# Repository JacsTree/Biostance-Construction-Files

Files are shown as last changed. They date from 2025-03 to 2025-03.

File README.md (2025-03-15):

# Biostance Device Assembly Instructions
This document is written for Northwestern DTC 1 Section 5.1.

*Adapted from the docs [here](https://docs.google.com/document/d/1ldEVrvwhGYVu4OGukCBJCGcmKfjVL98Qq2BRzPFvP7Y/edit?usp=sharing): (additional pictures can be found at the link)* 
## Introduction

This document provides step-by-step instructions for reproducing the final Biostance device prototype.  It covers the process from purchasing parts and assembling components to final construction and code implementation.  The device measures and logs a user's percent weight-bearing status over time.

**Estimated Assembly Time:** 9 hours (excluding drying/printing times) for someone proficient in the required techniques with pre-prepared materials.

**Skill Level:** Intermediate to advanced proficiency in 3D printing, soldering, woodworking/plastic cutting, and basic electronics.

**Recommendation:**  Read through *all* instructions and gather *all* materials and tools before starting.

## Parts List

### Components

| Component | Quantity | Notes |
| :--- | :--- | :--- |
| 50kg Load Cells | 8 | |
| Microcontroller (ESP32) | 1 | |
| PLA Filament (1.75mm) | 100g |  Color of your choice |
| 22 Gauge Wire | 8 x 1.5ft| Multiple Colors is helpful |
| 22 Gauge Wire | 8 x 8in  | Multiple Colors is helpful |
| Lithium Cell Battery | 1 |  Capacity and voltage compatible with your ESP32 (check specifications) |
| Battery Charger | 1 |  Compatible with your chosen battery |
| Grip Tape Roll | 1 x 30ft | |
| Hot Glue Sticks | 2 | |
| Epoxy Packets | 8 | |
| Rubber Feet Package | 1 | |
| Rosin Core Solder Wire | 3g | |
| Sturdy Material (Wood/Polycarb) | 3ft x 3ft | |
| 2 or 3-way Switch | 1 | |

### Tools

| Tool | Notes |
| :--- | :--- |
| 3D Printer |  With sufficient build volume for the largest part. |
| Bandsaw or Table Saw |  For cutting the base material. |
| Tape Measure | |
| Ruler | |
| Soldering Iron | |
| Wire Strippers | |
| Scissors | |
| Hot Glue Gun | Optional, but helpful for securing components. |
| Multimeter | Optional, but helpful for testing connections. |
| Razor Blade |  For cleaning up grip tape edges. |

## Safety Precautions

**Crucially, follow all safety instructions provided with your tools and materials.**  In addition, observe these precautions:

*   **Heat-Based Devices (3D Printer, Soldering Iron, Hot Glue Gun):**
    *   **Do NOT touch heated surfaces (nozzles, beds, etc.) until fully cooled.**
    *   **Do NOT touch melted material (filament, solder, glue) during operation.**
    *   **Allow sufficient cooling time for wires, PCB boards, and components near solder joints.  Heat can conduct through these parts.**
    *   Work in a well-ventilated area.

*   **Cutting Devices (Saws, Wire Strippers, Scissors, Razor Blade, Tape Measure):**
    *   **Exercise extreme caution to avoid cuts from sharp edges.**
    *   **Bandsaws/Table Saws present significant risks. Materials, clothing, or body parts can be caught and pulled into the blade.**
    *   **Operate these saws with *utmost* caution and follow *all* manufacturer safety guidelines.**
    *   Use appropriate safety equipment (eye protection, push sticks, etc.).
    *   Ensure the work area is clear of obstructions.
    *   Never reach over the blade.

* **Epoxy**
    * Work in a well ventilated area.
    * Wear gloves
    * Do not ingest

## Construction Steps

### Step 1: 3D Printing

1.  **File Locations:**
    *   **GitHub (this repository):**
        *   `Top of Box v2.stl`
        *   `Bottom of Box v4.stl` (Adjust file if using different bottom material thickness)
        *   `tip scale v2.stl`
    *   **Thingiverse (patrick3345):**
        *   `50kg Loadcell Bracket versionF`  [Link to Thingiverse page](https://www.thingiverse.com/thing:2624188/files) 

2.  **Printing Instructions:**
    *   Combine all files into a single print job if your build plate is large enough.
    *   **Slicer Settings:**
        *   Wall Thickness: 1.0 mm
        *   Infill: 50%
        *   Supports: Tree-style (auto-generated) 
        *   Recommended Slicers: Cura Slicer, PrusaSlicer, or Bambu Studio (Instructions below use Cura Slicer).
    *   **Placement:** Ensure models are *not* overlapping on the build plate.

4.  **Slice and Upload:** Slice the files using your chosen slicer and upload them to your 3D printer. Follow your printer's specific instructions for uploading files.

5.  **Post-Processing:**
    *   Allow the build plate to cool completely.
    *   Carefully remove the printed parts from the build plate.
    *   Remove any support structures.

### Step 2: Cut Structure Pieces and Assemble Base

1.  **Cutting:** Cut the sturdy material (wood/polycarbonate) into:
    *   One piece: 1.5ft x 3ft
    *   Two pieces: 1.5ft x 1.5ft

3.  **Load Cell Holder Placement:**
    *   Position the eight 3D-printed load cell holders on the *underside* of the 1.5ft x 3ft piece. These should be located where the corners of the 1.5ft x 1.5ft plates will eventually sit (refer to the image in the original instructions, which you should ideally include).
    *   **Securely epoxy the load cell holders in place.** Allow ample drying time according to the epoxy's instructions.

4.  **Rubber Feet:**
    *   Flip the 1.5ft x 3ft piece over.
    *   Attach rubber feet to the *opposite* side (the side *without* the load cell holders).  These should be positioned to align with the load cell holders.
    *   Epoxy the rubber feet in place.

5.  **Grip Tape (Top Pieces):**
    *   Apply grip tape to the *top* surfaces of the two 1.5ft x 1.5ft plates.
    *   Use a razor blade to carefully trim any excess grip tape for clean edges.

6.  **Load Cell Tips:**
    *   Attach the 3D-printed "tip scale v2.stl" pieces to the *top* of the 1.5ft x 1.5ft plates.
    *   Position each tip so it aligns with the *center* of a corresponding load cell holder on the base piece.
    *   Epoxy the tips in place.

### Step 3: Electronics, Wiring, and First Calibration

**Wiring Diagram:** Follow this diagram carefully throughout the wiring process.

**(Figure 1: Electronics wiring diagram displaying the function of each part.** 
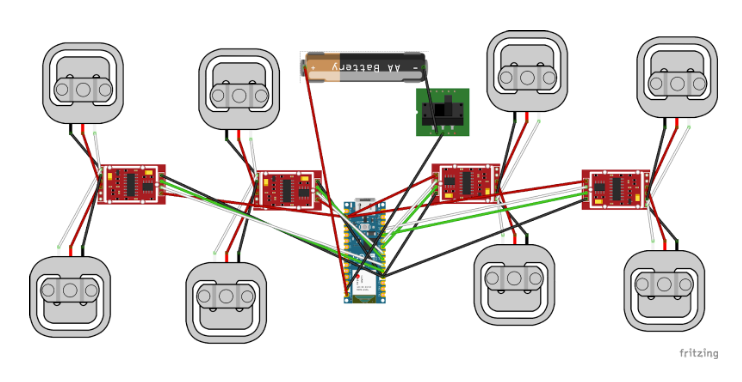
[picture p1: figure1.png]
Wiring Diagram

1.  **HX711 Modification (80Hz Mode):**
    *   **De-solder the 0 Ohm resistor** from *each* HX711 chip.
    *   **Bridge the 80Hz pads** with solder. This enables faster data transfer (at the cost of some accuracy).

2.  **Load Cell Wiring:** Solder the wires from *each* load cell to its corresponding HX711 module as shown in the wiring diagram.  **The colors of the load cell wires may vary; use a multimeter to identify the correct wires if necessary.**

3.  **HX711 Wire Lengths:**
    *   Attach approximately 1.3ft wires to the `VCC`, `GND`, `DT`, and `SCK` pins on *two* of the HX711 boards.  These will be the "outer" boards.
    *   Attach 8-inch wires to the `VCC`, `GND`, `DT`, and `SCK` pins on the other *two* HX711 boards.
    *   Place all load cells into their holders on the bottom piece, with the wires facing upwards.

4.  **HX711 to ESP32 Connections:**
    *   Solder the `DT` (Data) and `SCK` (Clock) pins from each HX711 to the appropriate GPIO pins on your ESP32, according to the wiring diagram.
    *   **If you use a different ESP32 board, you can choose different GPIO pins, but *you must update the pin numbers in the code accordingly*.**
    *   Connect all HX711 `VCC` pins together and then to a 3.3V or 5V pin on the ESP32 (depending on your ESP32's specifications and the HX711 operating voltage - check datasheets!).
    *   Connect all HX711 `GND` pins together and then to a `GND` pin on the ESP32.

5.  **Battery and Switch Wiring:**
    *   Solder the *negative* (-) wire from the battery connector to one terminal of the switch.
    *   Solder a wire from the *other* terminal of the switch to the `GND` pin of the ESP32.
    *   Solder the *positive* (+) wire from the battery connector to the `Vin` pin on the ESP32.
    *   **CRITICAL WARNING:** **If your battery voltage exceeds the ESP32's maximum input voltage (check the ESP32 datasheet!), you *must* add a voltage regulator (e.g., a 5V regulator) between the battery and the ESP32's `Vin` pin.  Failure to do so will damage the ESP32 and could cause a fire.**

6.  **Calibration (Test Code):**
    *   Upload the test code [here](https://github.com/bogde/HX711/blob/master/examples/HX711_full_example/HX711_full_example.ino) to the ESP32 using the Arduino IDE 2.x.
    *   **Arduino IDE Setup:**
        *   Ensure you have the ESP32 board definitions installed in the Arduino IDE.
        *   Select the correct ESP32 board and port.
        *   Set the "Partition Scheme" to a large enough size to accommodate the compiled code.
    *   **Calibration Procedure:** Follow the instructions *within the test code* to determine the calibration factor for *each* HX711.  Each HX711 represents a full Wheatstone bridge formed by two half-bridge load cells.  You'll likely need to place known weights on the scale to calibrate.  *Record these calibration factors; you'll need them later.*

### Step 4: Final Assembly

1.  **Box Attachment:** Epoxy the 3D-printed electronics box to the back of the bottom (1.5ft x 3ft) sheet.

2.  **Scale Top Attachment:** Carefully place the individual scale tops (1.5ft x 1.5ft pieces with grip tape and tips) onto the load cell sensors.  Ensure proper alignment. Epoxy this on top.
3.  **Wiring Management:**
    *   Carefully route the excess wiring into the 3D-printed electronics box.
    *   Securely mount the switch and battery connector to their respective holes in the box.
    *   Position the ESP32 and battery inside the box. You may want to use hot glue or other non-permanent adhesive to keep them from rattling around.

4.  **Final Code Upload:**
    *   Upload the final code to the ESP32.
    *   **Update the code with:**
        *   The correct GPIO pin numbers (if you used different pins than the example code).
        *   The calibration factors you determined in Step 3.6.

5.  **Box Top:** Epoxy the top of the 3D-printed box in place.

6.  **Final Grip Tape:** Apply grip tape around the sides of the device for aesthetics and to encourage users to lift it from the bottom.

## Conclusion

The Biostance device should now be complete. Thoroughly test all aspects of the device, including weight measurement and data logging. Ensure the graphs are working correctly.

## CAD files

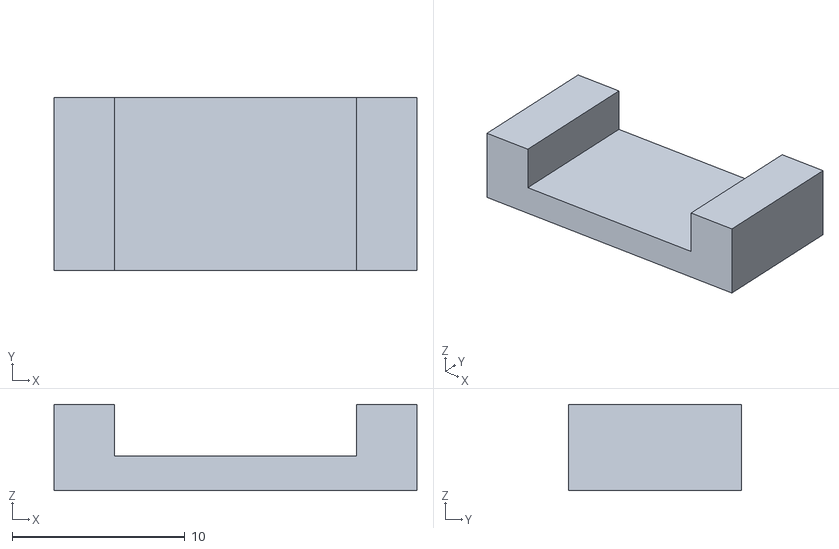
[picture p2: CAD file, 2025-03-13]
tip scale v2.stl
21.0 x 10.0 x 5.00

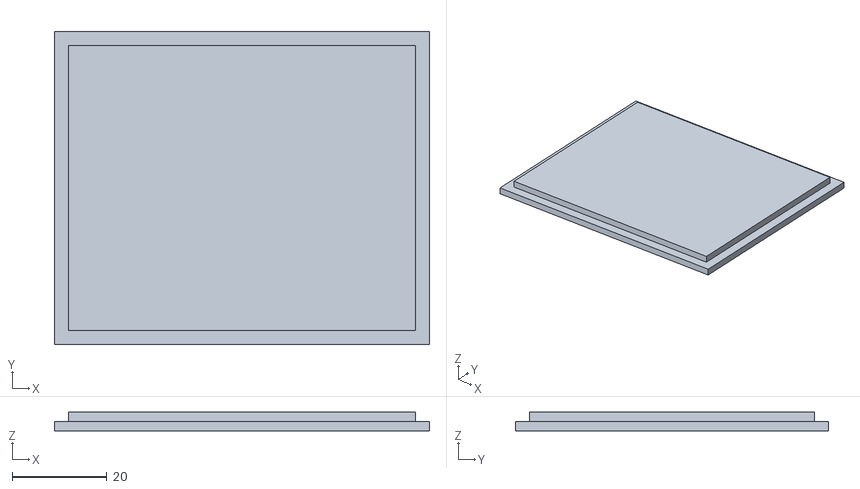
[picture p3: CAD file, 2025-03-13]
Top of Box v2.stl
79.0 x 66.0 x 4.00

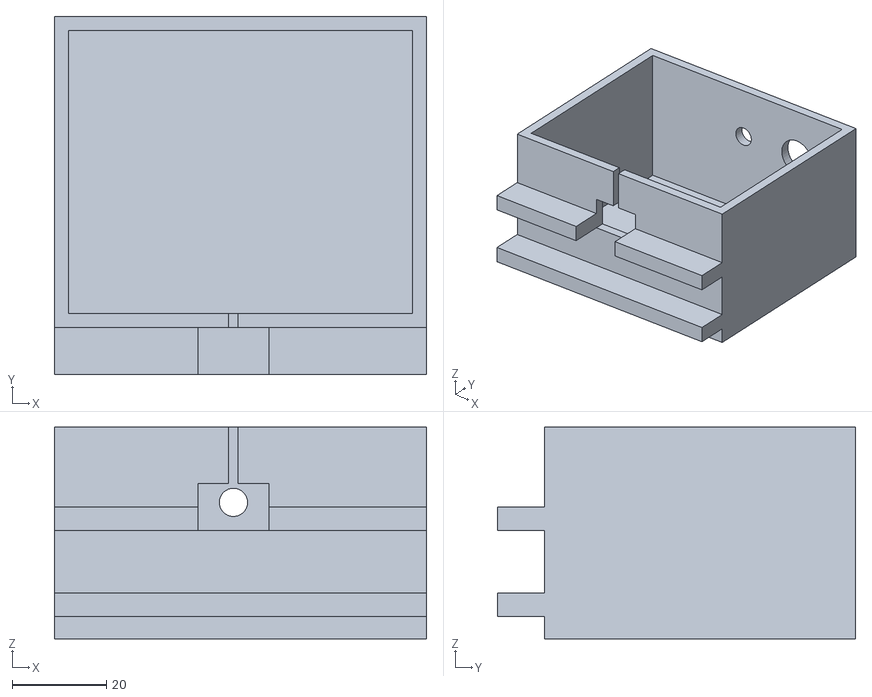
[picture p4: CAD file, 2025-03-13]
Bottom of Box v4.stl
79.0 x 76.0 x 45.0

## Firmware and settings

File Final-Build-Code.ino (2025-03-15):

#include <WiFi.h>
#include "HX711.h"
#include <ArduinoJson.h> 

const char* ssid     = "Biostance-Device";
const char* password = "9~fFx6Eg92s";
WiFiServer server(80);

// HX711 circuit wiring for each load cell
const int LOADCELL_DOUT_PIN_1 = 5;
const int LOADCELL_SCK_PIN_1 = 6;

const int LOADCELL_DOUT_PIN_2 = 7;
const int LOADCELL_SCK_PIN_2 = 8;

const int LOADCELL_DOUT_PIN_3 = 9;
const int LOADCELL_SCK_PIN_3 = 10;

const int LOADCELL_DOUT_PIN_4 = 17;
const int LOADCELL_SCK_PIN_4 = 18;

HX711 scale1;
HX711 scale2;
HX711 scale3;
HX711 scale4;

// Calibration factors for each load cell.  REPLACE these!
const float calibration_factor_1 = -19757.279; //RR good
const float calibration_factor_2 = -20911.6; //RL g
const float calibration_factor_3 = -20678.8955; //LR good
const float calibration_factor_4 = -19000.304; //LL g

// Data refresh interval (milliseconds)
const unsigned long DATA_REFRESH_INTERVAL = 200; // Update every 200 milliseconds
const unsigned long CLIENT_TIMEOUT = 10000;  // 10 seconds of inactivity

unsigned long lastDataUpdate = 0;

void sendHTML(WiFiClient& client);
void sendData(WiFiClient& client);



void setup() {
  
  // Initialize HX711s
  scale1.begin(LOADCELL_DOUT_PIN_1, LOADCELL_SCK_PIN_1);
  scale1.set_scale(calibration_factor_1);
  scale1.tare();

  scale2.begin(LOADCELL_DOUT_PIN_2, LOADCELL_SCK_PIN_2);
  scale2.set_scale(calibration_factor_2);
  scale2.tare();

  scale3.begin(LOADCELL_DOUT_PIN_3, LOADCELL_SCK_PIN_3);
  scale3.set_scale(calibration_factor_3);
  scale3.tare();

  scale4.begin(LOADCELL_DOUT_PIN_4, LOADCELL_SCK_PIN_4);
  scale4.set_scale(calibration_factor_4);
  scale4.tare();

  WiFi.softAP(ssid, password);
  IPAddress IP = WiFi.softAPIP();
  server.begin();
}

void loop() {
  WiFiClient client = server.available();

  if (client) {
    char header[2000] = {0}; 
    String currentLine = "";
    unsigned long lastActivity = millis(); 
    bool initialRequest = true;

    while (client.connected() && (millis() - lastActivity < CLIENT_TIMEOUT)) {
      if (client.available()) {
        char c = client.read();
        strncat(header, &c, 1); 

        if (c == '\n') {
          if (currentLine.length() == 0) {

             if (strstr(header, "GET /data") != NULL) {
              sendData(client); 
              break; 
            }

            sendHTML(client);  
            break; 

          } else {
            currentLine = "";
          }
        } else if (c != '\r') {
          currentLine += c;
        }
        lastActivity = millis(); 
      }
      yield();
    }

    client.stop();
  }


  yield();
}



void sendHTML(WiFiClient& client) {
  client.println("HTTP/1.1 200 OK");
  client.println("Content-type:text/html");
  client.println("Connection: close");
  client.println("Cache-Control: no-cache, no-store, must-revalidate");
  client.println("Pragma: no-cache");
  client.println("Expires: 0");
  client.println();
client.print(R"=====(
<!DOCTYPE html>
<html>
<head>
<script>
!function(t,e){"object"==typeof exports&&"undefined"!=typeof module?module.exports=e():"function"==typeof define&&define.amd?define(e):(t="undefined"!=typeof globalThis?globalThis:t||self).Chart=e()}(this,(function(){"use strict";var t=Object.freeze({__proto__:null,get Colors(){return Go},get Decimation(){return Qo},get Filler(){return ma},get Legend(){return ya},get SubTitle(){return ka},get Title(){return Ma},get Tooltip(){return Ba}});function e(){}const i=(()=>{let t=0;return()=>t++})();function s(t){return null==t}function n(t){if(Array.isArray&&Array.isArray(t))return!0;const e=Object.prototype.toString.call(t);return"[object"===e.slice(0,7)&&"Array]"===e.slice(-6)}function o(t){return null!==t&&"[object Object]"===Object.prototype.toString.call(t)}function a(t){return("number"==typeof t||t instanceof Number)&&isFinite(+t)}function r(t,e){return a(t)?t:e}function l(t,e){return void 0===t?e:t}const h=(t,e)=>"string"==typeof t&&t.endsWith("%")?parseFloat(t)/100:+t/e,c=(t,e)=>"string"==typeof t&&t.endsWith("%")?parseFloat(t)/100*e:+t;function d(t,e,i){if(t&&"function"==typeof t.call)return t.apply(i,e)}function u(t,e,i,s){let a,r,l;if(n(t))if(r=t.length,s)for(a=r-1;a>=0;a--)e.call(i,t[a],a);else for(a=0;a<r;a++)e.call(i,t[a],a);else if(o(t))for(l=Object.keys(t),r=l.length,a=0;a<r;a++)e.call(i,t[l[a]],l[a])}function f(t,e){let i,s,n,o;if(!t||!e||t.length!==e.length)return!1;for(i=0,s=t.length;i<s;++i)if(n=t[i],o=e[i],n.datasetIndex!==o.datasetIndex||n.index!==o.index)return!1;return!0}function g(t){if(n(t))return t.map(g);if(o(t)){const e=Object.create(null),i=Object.keys(t),s=i.length;let n=0;for(;n<s;++n)e[i[n]]=g(t[i[n]]);return e}return t}function p(t){return-1===["__proto__","prototype","constructor"].indexOf(t)}function m(t,e,i,s){if(!p(t))return;const n=e[t],a=i[t];o(n)&&o(a)?x(n,a,s):e[t]=g(a)}function x(t,e,i){const s=n(e)?e:[e],a=s.length;if(!o(t))return t;const r=(i=i||{}).merger||m;let l;for(let e=0;e<a;++e){if(l=s[e],!o(l))continue;const n=Object.keys(l);for(let e=0,s=n.length;e<s;++e)r(n[e],t,l,i)}return t}function b(t,e){return x(t,e,{merger:_})}function _(t,e,i){if(!p(t))return;const s=e[t],n=i[t];o(s)&&o(n)?b(s,n):Object.prototype.hasOwnProperty.call(e,t)||(e[t]=g(n))}const y={"":t=>t,x:t=>t.x,y:t=>t.y};function v(t){const e=t.split("."),i=[];let s="";for(const t of e)s+=t,s.endsWith("\\")?s=s.slice(0,-1)+".":(i.push(s),s="");return i}function M(t,e){const i=y[e]||(y[e]=function(t){const e=v(t);return t=>{for(const i of e){if(""===i)break;t=t&&t[i]}return t}}(e));return i(t)}function w(t){return t.charAt(0).toUpperCase()+t.slice(1)}const k=t=>void 0!==t,S=t=>"function"==typeof t,P=(t,e)=>{if(t.size!==e.size)return!1;for(const i of t)if(!e.has(i))return!1;return!0};function D(t){return"mouseup"===t.type||"click"===t.type||"contextmenu"===t.type}const C=Math.PI,O=2*C,A=O+C,T=Number.POSITIVE_INFINITY,L=C/180,E=C/2,R=C/4,I=2*C/3,z=Math.log10,F=Math.sign;function V(t,e,i){return Math.abs(t-e)<i}function B(t){const e=Math.round(t);t=V(t,e,t/1e3)?e:t;const i=Math.pow(10,Math.floor(z(t))),s=t/i;return(s<=1?1:s<=2?2:s<=5?5:10)*i}function W(t){const e=[],i=Math.sqrt(t);let s;for(s=1;s<i;s++)t%s==0&&(e.push(s),e.push(t/s));return i===(0|i)&&e.push(i),e.sort(((t,e)=>t-e)).pop(),e}function N(t){return!function(t){return"symbol"==typeof t||"object"==typeof t&&null!==t&&!(Symbol.toPrimitive in t||"toString"in t||"valueOf"in t)}(t)&&!isNaN(parseFloat(t))&&isFinite(t)}function H(t,e){const i=Math.round(t);return i-e<=t&&i+e>=t}function j(t,e,i){let s,n,o;for(s=0,n=t.length;s<n;s++)o=t[s][i],isNaN(o)||(e.min=Math.min(e.min,o),e.max=Math.max(e.max,o))}function $(t){return t*(C/180)}function Y(t){return t*(180/C)}function U(t){if(!a(t))return;let e=1,i=0;for(;Math.round(t*e)/e!==t;)e*=10,i++;return i}function X(t,e){const i=e.x-t.x,s=e.y-t.y,n=Math.sqrt(i*i+s*s);let o=Math.atan2(s,i);return o<-.5*C&&(o+=O),{angle:o,distance:n}}function q(t,e){return Math.sqrt(Math.pow(e.x-t.x,2)+Math.pow(e.y-t.y,2))}function K(t,e){return(t-e+A)%O-C}function G(t){return(t%O+O)%O}function Z(t,e,i,s){const n=G(t),o=G(e),a=G(i),r=G(o-n),l=G(a-n),h=G(n-o),c=G(n-a);return n===o||n===a||s&&o===a||r>l&&h<c}function J(t,e,i){return Math.max(e,Math.min(i,t))}function Q(t){return J(t,-32768,32767)}function tt(t,e,i,s=1e-6){return t>=Math.min(e,i)-s&&t<=Math.max(e,i)+s}function et(t,e,i){i=i||(i=>t[i]<e);let s,n=t.length-1,o=0;for(;n-o>1;)s=o+n>>1,i(s)?o=s:n=s;return{lo:o,hi:n}}const it=(t,e,i,s)=>et(t,i,s?s=>{const n=t[s][e];return n<i||n===i&&t[s+1][e]===i}:s=>t[s][e]<i),st=(t,e,i)=>et(t,i,(s=>t[s][e]>=i));function nt(t,e,i){let s=0,n=t.length;for(;s<n&&t[s]<e;)s++;for(;n>s&&t[n-1]>i;)n--;return s>0||n<t.length?t.slice(s,n):t}const ot=["push","pop","shift","splice","unshift"];function at(t,e){t._chartjs?t._chartjs.listeners.push(e):(Object.defineProperty(t,"_chartjs",{configurable:!0,enumerable:!1,value:{listeners:[e]}}),ot.forEach((e=>{const i="_onData"+w(e),s=t[e];Object.defineProperty(t,e,{configurable:!0,enumerable:!1,value(...e){const n=s.apply(this,e);return t._chartjs.listeners.forEach((t=>{"function"==typeof t[i]&&t[i](...e)})),n}})})))}function rt(t,e){const i=t._chartjs;if(!i)return;const s=i.listeners,n=s.indexOf(e);-1!==n&&s.splice(n,1),s.length>0||(ot.forEach((e=>{delete t[e]})),delete t._chartjs)}function lt(t){const e=new Set(t);return e.size===t.length?t:Array.from(e)}const ht="undefined"==typeof window?function(t){return t()}:window.requestAnimationFrame;function ct(t,e){let i=[],s=!1;return function(...n){i=n,s||(s=!0,ht.call(window,(()=>{s=!1,t.apply(e,i)})))}}function dt(t,e){let i;return function(...s){return e?(clearTimeout(i),i=setTimeout(t,e,s)):t.apply(this,s),e}}const ut=t=>"start"===t?"left":"end"===t?"right":"center",ft=(t,e,i)=>"start"===t?e:"end"===t?i:(e+i)/2,gt=(t,e,i,s)=>t===(s?"left":"right")?i:"center"===t?(e+i)/2:e;function pt(t,e,i){const n=e.length;let o=0,a=n;if(t._sorted){const{iScale:r,vScale:l,_parsed:h}=t,c=t.dataset&&t.dataset.options?t.dataset.options.spanGaps:null,d=r.axis,{min:u,max:f,minDefined:g,maxDefined:p}=r.getUserBounds();if(g){if(o=Math.min(it(h,d,u).lo,i?n:it(e,d,r.getPixelForValue(u)).lo),c){const t=h.slice(0,o+1).reverse().findIndex((t=>!s(t[l.axis])));o-=Math.max(0,t)}o=J(o,0,n-1)}if(p){let t=Math.max(it(h,r.axis,f,!0).hi+1,i?0:it(e,d,r.getPixelForValue(f),!0).hi+1);if(c){const e=h.slice(t-1).findIndex((t=>!s(t[l.axis])));t+=Math.max(0,e)}a=J(t,o,n)-o}else a=n-o}return{start:o,count:a}}function mt(t){const{xScale:e,yScale:i,_scaleRanges:s}=t,n={xmin:e.min,xmax:e.max,ymin:i.min,ymax:i.max};if(!s)return t._scaleRanges=n,!0;const o=s.xmin!==e.min||s.xmax!==e.max||s.ymin!==i.min||s.ymax!==i.max;return Object.assign(s,n),o}class xt{constructor(){this._request=null,this._charts=new Map,this._running=!1,this._lastDate=void 0}_notify(t,e,i,s){const n=e.listeners[s],o=e.duration;n.forEach((s=>s({chart:t,initial:e.initial,numSteps:o,currentStep:Math.min(i-e.start,o)})))}_refresh(){this._request||(this._running=!0,this._request=ht.call(window,(()=>{this._update(),this._request=null,this._running&&this._refresh()})))}_update(t=Date.now()){let e=0;this._charts.forEach(((i,s)=>{if(!i.running||!i.items.length)return;const n=i.items;let o,a=n.length-1,r=!1;for(;a>=0;--a)o=n[a],o._active?(o._total>i.duration&&(i.duration=o._total),o.tick(t),r=!0):(n[a]=n[n.length-1],n.pop());r&&(s.draw(),this._notify(s,i,t,"progress")),n.length||(i.running=!1,this._notify(s,i,t,"complete"),i.initial=!1),e+=n.length})),this._lastDate=t,0===e&&(this._running=!1)}_getAnims(t){const e=this._charts;let i=e.get(t);return i||(i={running:!1,initial:!0,items:[],listeners:{complete:[],progress:[]}},e.set(t,i)),i}listen(t,e,i){this._getAnims(t).listeners[e].push(i)}add(t,e){e&&e.length&&this._getAnims(t).items.push(...e)}has(t){return this._getAnims(t).items.length>0}start(t){const e=this._charts.get(t);e&&(e.running=!0,e.start=Date.now(),e.duration=e.items.reduce(((t,e)=>Math.max(t,e._duration)),0),this._refresh())}running(t){if(!this._running)return!1;const e=this._charts.get(t);return!!(e&&e.running&&e.items.length)}stop(t){const e=this._charts.get(t);if(!e||!e.items.length)return;const i=e.items;let s=i.length-1;for(;s>=0;--s)i[s].cancel();e.items=[],this._notify(t,e,Date.now(),"complete")}remove(t){return this._charts.delete(t)}}var bt=new xt;
/*!
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
